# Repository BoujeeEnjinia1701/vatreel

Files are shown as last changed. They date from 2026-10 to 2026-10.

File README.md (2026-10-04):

# VatReel

     

**Area:** Advanced manufacturing · **TRL:** 3 of 9 (proof of concept on paper) · **Value-engineering target:** $1,500 USD · **Difficulty:** 2 of 5

Moves hides and yarn through pits and dye vats on a hand-cranked reel so hands never enter the liquor.

> CONCEPT, NOT FOR FABRICATION. VatReel is a TRL 3 design on paper: it has not been built or tested.

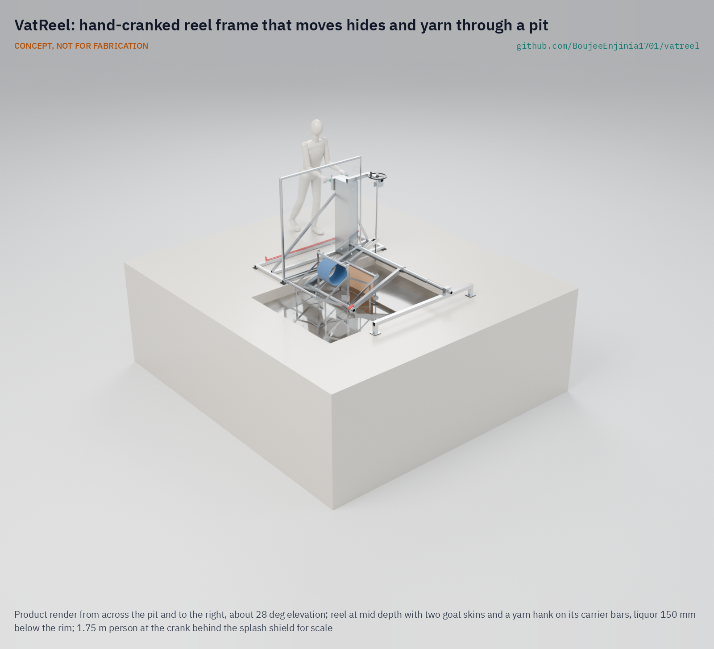
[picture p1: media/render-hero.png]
VatReel: hand-cranked reel frame that moves hides and yarn through a pit, product render


[Concept render](media/hero.png) · [Exploded view](media/exploded.png) · [Interactive 3D model](media/viewer.html) · [Concept blueprint (PDF)](media/concept-blueprint.pdf) · [General arrangement VTR-DWG-001 (PDF)](cad/drawings/VTR-DWG-001.pdf) · [Sizing note VTR-CAL-001](docs/04-calcs/01-sizing.md) · [Prototype build plan](docs/05-build-plan.md) · [Design decisions](docs/06-design-decisions.md) · [Review note](docs/REVIEW.md)

## Concept rationale

The liquor is the hazard, and the hands are the route in. Industrial dye houses solved this long ago with the winch, a reel that lifts cloth in and out of the bath, but those machines are fixed, powered and sized for factories. VatReel keeps the reel and drops everything else: a portable frame set across an existing pit or vat, a hand crank, and carriers that hold hides or hanks of yarn. The worker loads dry-side, cranks, and the reel carries the load through the liquor.

It is meant for workshops that will not buy a drum or a dyeing machine. The frame spans the pits they already have, it is built from stock sections and corrosion-resistant sheet, and every part can be cut, drilled and bolted with hand tools. Publishing it openly lets a local fabricator build it and a cooperative adapt it to its own pit sizes.

## Burning platform

In Hazaribagh, Dhaka, Human Rights Watch counted about 150 tanneries and 8,000 to 12,000 workers, and recorded workers climbing into pits to pull hides out by hand; one described acid falling on a colleague's arm so that the flesh came off ([HRW, 2012](https://www.hrw.org/report/2012/10/09/toxic-tanneries/health-repercussions-bangladeshs-hazaribagh-leather)). In Kanpur, India, tannery workers with moderate or high skin contact with chemicals were 35 times more likely to report scaling with fissures than those with low exposure, and 22 % of tannery workers reported itching and fissured hands against 7.3 % of other workers ([Kashyap et al., 2021](https://pmc.ncbi.nlm.nih.gov/articles/PMC8530047)).

The dose is not only on the skin. Among 120 tannery workers in Sialkot, Pakistan, 54 % had blood chromium above the ATSDR safety threshold and 13 % had skin rashes ([Khan et al., 2013](https://journals.sagepub.com/doi/10.1177/0748233711430974)). In hand dyeing, the UK Health and Safety Executive notes that some dyes cause allergic skin reactions and that harsh cleaning to remove colour from skin can itself cause dermatitis ([HSE](https://www.hse.gov.uk/textiles/dyes-dyeing.htm)).

## Where it could be used

### By industry

| Industry | Use |
| --- | --- |
| Small and informal tanneries | Moving hides through soaking, liming, pickling and tanning pits without workers entering or reaching into the liquor |
| Hand and craft dyeing | Carrying hanks of yarn or lengths of cloth through hot or indigo vats at an even pace |
| Heritage and tourist workshops | Keeping traditional pit processes while taking the worker's body out of the bath |
| Leather and textile supply chains | A low-cost engineering control that brands and auditors can point small suppliers to |
| Vocational and technical colleges | Teaching model for reel, gear and corrosion design in wet process industries |

### By country or region

| Country or region | Why it matters there |
| --- | --- |
| Bangladesh | Hazaribagh workers told Human Rights Watch they climb into pits and lift hides out by hand while liquor splashes their skin ([HRW, 2012](https://www.hrw.org/report/2012/10/09/toxic-tanneries/health-repercussions-bangladeshs-hazaribagh-leather)). |
| India | In Kanpur, 18 % of tannery workers reported scaling with fissures on the hands, against 3.8 % of non-tannery workers ([Kashyap et al., 2021](https://pmc.ncbi.nlm.nih.gov/articles/PMC8530047)). |
| Pakistan | More than half of the Sialkot tannery workers studied had blood chromium above the ATSDR threshold ([Khan et al., 2013](https://journals.sagepub.com/doi/10.1177/0748233711430974)). |
| Morocco | At the Chouara tannery in Fez, about 200 men work, standing thigh-deep in chromium-laden vats to move hides ([Living on Earth](https://www.loe.org/shows/segments.html?programID=14-P13-00044&segmentID=4)). |
| Nigeria | Dyers at Kano's Kofar Mata pits, traced back more than 500 years, still dip cloth again and again into deep in-ground vats of fermented indigo ([Wikipedia](https://en.wikipedia.org/wiki/Kofar_Mata_Dye_Pits)). |

## What sparked the idea

The idea came from a single line in the Human Rights Watch report on Hazaribagh. A worker described how the job is done: they get inside the pit, take the hides with their hands and throw them out, and even with gloves and boots the water splashes on their skin. Another recalled acid falling on a colleague's arm until the bone showed ([HRW, 2012](https://www.hrw.org/report/2012/10/09/toxic-tanneries/health-repercussions-bangladeshs-hazaribagh-leather)). The hazard comes from a hand task that a crank and a reel could do instead.

## Problem

In small tanneries and hand-dyeing workshops, workers reach, wade or stand in pits of acid, chromium and dye liquor to move hides and yarn through the bath. Their skin takes the dose every shift.

Full problem statement: [docs/01-problem.md](docs/01-problem.md)

## Concept

A portable hand-cranked reel frame set across a tannery pit or dye vat; workers load hides or yarn onto the reel and crank it to carry them through the liquor, so their hands never enter the bath. A stainless frame spans pits 1.0 to 2.5 m wide; the reel rides on two arms that swing on a pivot tube across the pit, and a self-locking lift screw sets how deep it dips (the lowest carrier bar 0.3 to 1.0 m below the rim) or lifts it clear. Every carrier bar comes up above the rim to be loaded with long hooks from behind a splash shield. On paper the crank needs about 90 N with a 25 kg wet load on one bar, and the parts cost about $1,437 against the $1,500 value-engineering target.

Full design precis: [docs/02-concept.md](docs/02-concept.md) · Requirements: [docs/03-requirements.md](docs/03-requirements.md)

## Key components

- Near stand (base frame and bearing tower) and far stand, joined by a telescopic pivot tube
- Arm frame swinging on the pivot tube
- Reel with six carrier bars and snap hooks
- Hand crank with a two-stage roller chain drive, 6 to 1, fully enclosed
- Ratchet and pawl brake
- Self-locking lift screw with a handwheel (in place of a lift lever)
- Splash shield
- Loading hooks

## Building the prototype

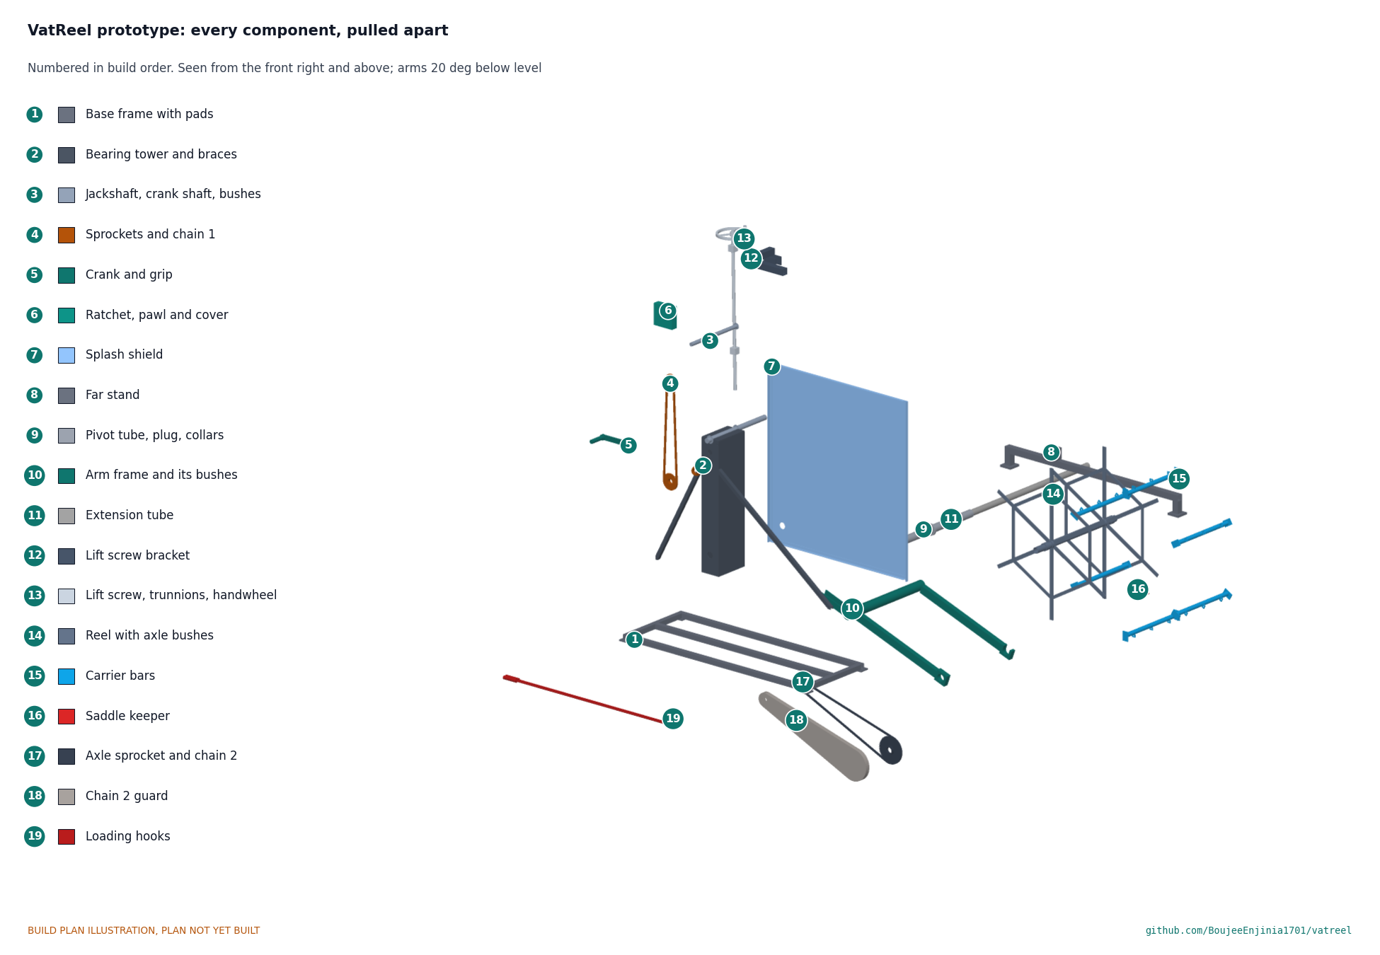
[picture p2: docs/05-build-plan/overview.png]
Every component of the VatReel prototype, pulled apart and numbered in build order


The [prototype build plan](docs/05-build-plan.md) (VTR-BLD-001, plan, not yet built) shows how to make each component and fit it to the next, in 16 making sketches, 11 joint close-ups and 13 assembly steps drawn from the model. The frame, arms and reel are sawn, drilled and welded from 304 and 316L stainless tube, bar and plate, with no casting or lathe work; the chains, sprockets, bushes and lift screw are bought. Writing the plan made the design constructable: eighteen changes, such as a torque tube joining the arms, a closed chain guard and an open saddle that lets the reel drop in without anyone reaching over the pit, are recorded in [VTR-DDR-002](docs/decisions/0002-design-for-construction.md). The parts cost about $1,437, $63 under the $1,500 value-engineering target, a hypothetical control target.

## Safety

> Published as an open engineering reference, not certified equipment. Builders and users are responsible for their own risk assessment.
>
> The reel reduces skin contact but does not remove the need for gloves, eye protection and boots.
>
> Nip points at the crank gear and reel must be guarded; loose clothing and long hair must be kept clear.
>
> The frame must not create a trip or fall hazard at the pit edge; the pit rim must be checked before placing the stands.
>
> Hot baths near 98 °C (208 °F) add a scald hazard; the splash shield and the self-locking lift are part of the design, not options, and two people are present at any bath above 60 °C.
>
> The reel and its load (up to about 55 kg) hang over the pit; the lift screw is self-locking and the ratchet holds the reel, and the chains, sprockets and ratchet are enclosed. Never reach toward the reel unless it is stopped, the ratchet is engaged and the arms are wound up. The build plan lists the safety stops (VTR-BLD-001, section 6).
>
> This design is published as an open engineering reference. It is not certified equipment.

## Repository layout

| Folder | Contents |
| --- | --- |
| `docs/` | Problem, concept, requirements, calculations and design decisions |
| `cad/src/` | build123d Python source, the source of truth for all geometry |
| `cad/step/`, `cad/stl/` | Exported models for FreeCAD, other CAD tools and printing |
| `cad/drawings/` | 2D sketches and dimensioned drawings |
| `bom/` | Bill of materials |
| `electronics/` | KiCad schematics and PCB layouts |
| `firmware/` | Microcontroller code |
| `media/` | Renders, perspectives and photos |
| `build-log/` | Dated prototyping notes |

## Documentation

Controlled documents follow the portfolio [documentation standard](.kit/STANDARDS.md). Each carries a document ID (VTR-PRC-001 for the precis), a version and a revision history. Branded PDFs are built with `python .kit/render.py` and attached to GitHub Releases when a document is tagged, for example `VTR-PRC-001/v1.0`.

## Credits

Designed by Amish Chadha at Design Molecule Labs. See [CONTRIBUTORS.md](CONTRIBUTORS.md) for roles. To cite this design, use [CITATION.cff](CITATION.cff) (GitHub shows it as "Cite this repository").

AI assistance (Claude) was used to accelerate prototype documentation and first-pass research. Design direction and all decisions are Amish Chadha's, recorded in this repository's decision records (`docs/decisions/`).

## Licenses

- **Hardware** (CAD, drawings, BOM, electronics): [CERN-OHL-S v2](LICENSE)
- **Software** (firmware, scripts, notebooks): [MIT](LICENSE-SOFTWARE)

A project of [Design Molecule Labs](https://designmolecule.com).

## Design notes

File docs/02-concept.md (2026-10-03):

---
doc_id: VTR-PRC-001
title: VatReel design precis
project: VatReel
doc_type: Precis
version: "0.3"
status: Draft
date: '2026-10-03'
author: Amish Chadha
license: CERN-OHL-S-2.0
revisions:
- version: "0.1"
  date: '2026-09-30'
  author: Amish Chadha
  change: Initial scaffold
- version: "0.2"
  date: '2026-10-03'
  author: Amish Chadha
  change: TRL 2 concept formulated with concept media; arm-carried reel, two-stage chain drive, self-locking lift; decisions under Amish's pre-approval (VTR-DDR-001)
- version: "0.3"
  date: '2026-10-03'
  author: Amish Chadha
  change: TRL 3; first-order numbers from VTR-CAL-001; constructable design (VTR-DDR-002); build plan VTR-BLD-001 and register VTR-DEC-001
---

# VatReel design precis

Moves hides and yarn through pits and dye vats on a hand-cranked reel so hands never enter the liquor.

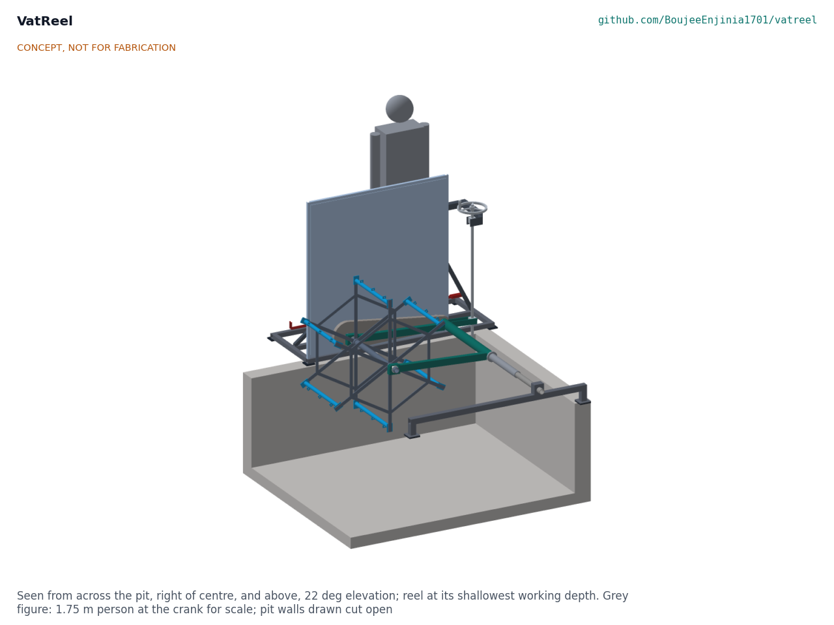
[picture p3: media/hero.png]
Figure 1. VatReel over a pit, reel at its shallowest working depth


*Figure 1. Concept render from the model: the near stand with its crank and splash shield on the operator's rim, the pivot tube across the pit to the far stand, and the reel on its arms.*

## How it works

A frame sits across the pit from rim to rim: a near stand on the operator's side and a far stand on the opposite rim, joined by a pivot tube that runs across the pit 200 mm above the rim, close to one end wall. Two arms swing on that pivot line and carry the reel at their ends; the reel's axle points across the pit, toward the operator. The operator turns a crank on the near stand, 1.0 m above the floor; two roller chains, the first inside the stand and the second in a closed case along the near arm, turn the reel at one sixth of the crank speed. Hides hang from snap hooks on six carrier bars, and hanks of yarn loop over them; as the reel turns, each bar goes down through the liquor and comes back up above the rim, where it is loaded, drained or unloaded with long hooks from behind a splash shield. A handwheel on a self-locking lift screw sets the arm angle, which sets how deep the reel dips (the lowest bar 300 to 1,000 mm below the rim) and, wound fully up, lifts every bar clear of the rim. A ratchet on the crank shaft holds the reel wherever it stops.

*Figure 2. Drive train at the worst case (estimates, VTR-CAL-001).*

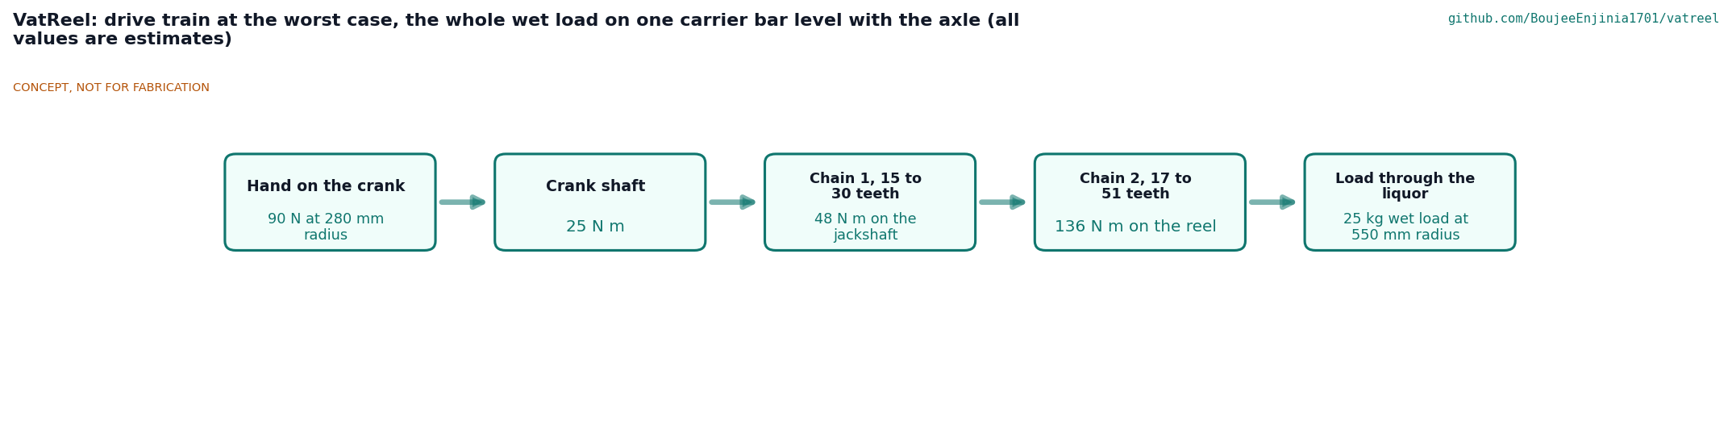
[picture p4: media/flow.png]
Figure 2. Drive train


## Components

*Table 1. Components (numbers match bom/bom.csv and the exploded view).*

| # | Component | Role |
| --- | --- | --- |
| 1, 2 | Near stand: base frame and bearing tower | Sits on the operator's rim; carries the crank, both shafts, chain 1 and the lift screw |
| 3, 4, 5 | Jackshaft, crank shaft and crank, ratchet and pawl | Turn and hold the reel |
| 6 | Splash shield | Translucent polypropylene in a stainless frame between the reel and the operator |
| 7, 8 | Lift screw bracket, lift screw, trunnions and handwheel | Set the depth and lift the reel; self-locking |
| 9, 10, 11 | Bushes, sprockets, roller chains | Two-stage 6 to 1 drive |
| 12, 13, 14 | Pivot tube, extension tube, far stand | Span pits 1.0 to 2.5 m wide |
| 16, 17 | Arm frame (torque tube and two arms), chain 2 guard | Carry the reel and enclose chain 2 |
| 18, 19 | Reel (axle and two spiders), carrier bars with snap hooks | Carry the load through the liquor |
| 15, 20, 22 | Rubber pads, loading hooks, assembly bar | Footing, hands-off loading, carrying the reel |

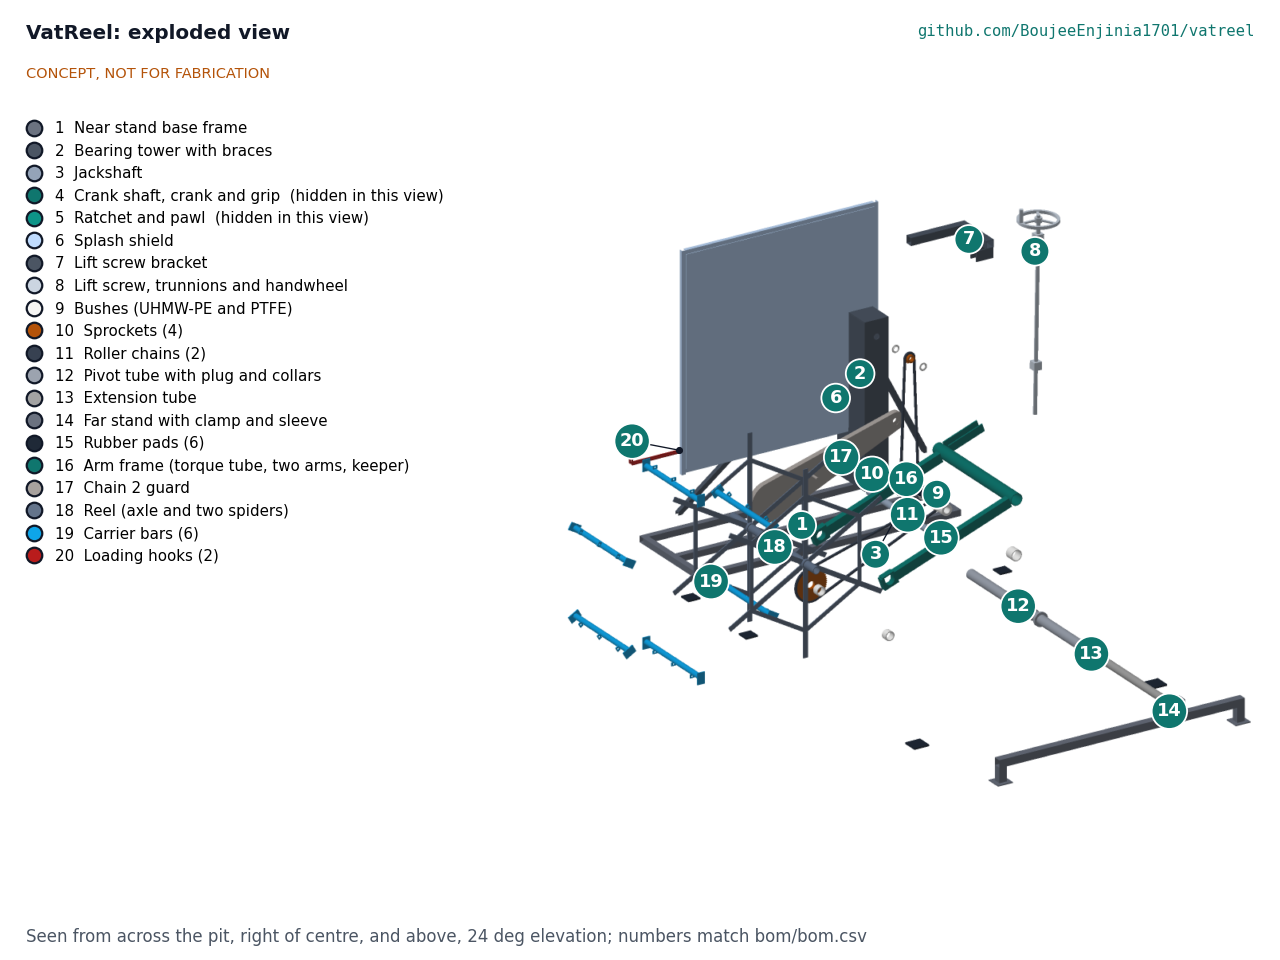
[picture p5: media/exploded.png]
Figure 3. Exploded view


*Figure 3. Exploded view with BOM numbers.*

## Key design choices

All were decided on 2026-10-03 under Amish's pre-approval and are recorded in VTR-DDR-001 (TRL 2) and VTR-DDR-002 (design for construction); VTR-DEC-001 indexes them.

- **Reel on swinging arms, not on a shaft across the pit.** A shaft spanning 1.0 to 2.5 m pits would have to telescope while turning; instead the static pivot tube telescopes and the reel stays 0.6 m long, close to the operator's rim.
- **Crank at a fixed height.** The first chain runs inside the stand from the crank to a jackshaft on the pivot line, the second along the arm, so the crank stays 1.0 m above the floor at every depth.
- **Self-locking lift screw in place of a free lift lever.** The reel and load weigh up to 55 kg; a screw cannot let them drop into a hot bath, and holds at any height.
- **Stainless throughout:** 316L for everything that goes into the liquor, 304 for the frame; glass-filled PTFE bushes in the liquor and UHMW-PE above it.
- **Everything moving is enclosed** except the reel itself, which is in the pit: chain 1 and the ratchet inside the stand, chain 2 in a closed case.

## First-order numbers

*Table 2. Key figures (estimates from VTR-CAL-001).*

| Quantity | Value | Assumption |
| --- | --- | --- |
| Reel | 1.18 m over the spokes, 0.6 m long, six bars at 550 mm radius | |
| Lowest bar below the rim | 300 to 1,000 mm, any depth between | Liquor 150 mm below the rim |
| Pits served | 1.0 to 2.52 m wide, at least 1.89 m long | Pivot 350 mm in from the end wall |
| Crank force | 90 N | 25 kg wet load all on one bar, level with the axle |
| Reel speed | 5 rpm, bars at 0.29 m/s | 30 rpm at the crank |
| Lift screw | 63 turns end to end, 79 N at the handwheel at 1.5 x | Thread friction 0.15 |
| Mass | 171 kg in all; heaviest carry 29.6 kg by two people | Model solids |
| Parts cost | USD 1,437 | Value-engineering target USD 1,500; USD 63 under |

## Patent design-arounds

From the preliminary patent, trademark and prior-art screen (not legal advice):

- Portable, manual version of the public-domain winch beck; the closest patent found, US3513672A, has expired.
- Watch items from the preliminary screen: corrosion of wetted parts and crank load. Both are addressed in VTR-CAL-001 (R6 at risk until coupon tests; crank force 90 N).

## Shared blocks

- The proposed hand capstan common block (SaltDrag, SiltHaul) is not used: the reel rises and falls, so VatReel needs its own two-stage chain drive (VTR-DDR-001).
- CalRig is the first candidate for the R5 proof-load test at TRL 4.

## Safety

> **Safety:** Published as an open engineering reference, not certified equipment. Builders and users are responsible for their own risk assessment.
>
> **Hazards.** Corrosive liquors (lime, sulphides, acids, chromium salts) and, in dyeing, baths near 98 °C (208 °F) that scald; an open pit edge with wet floors; moving machinery (the reel, two roller chains, a ratchet and a lift screw); a 55 kg reel and load hanging over the pit; lifts of up to 30 kg by two people during setup.
>
> **What the design does about them.** Hands stay out of the liquor: every bar comes up above the rim to be loaded with long hooks. The splash shield stands between the reel and the operator. The chains, sprockets and ratchet are enclosed. The lift screw is self-locking and the ratchet holds the reel, so nothing falls when the handwheel or crank is let go. The stands sit back from the pit edge on rubber pads.
>
> **What the user must still do.** Wear gloves, eye protection and boots; keep loose clothing and long hair clear of the crank; never reach over the shield or into the pit while the reel can turn; do not work alone at a hot bath; check the pit rim before placing the stands. The shield is not a guardrail.
>
> This design is published as an open engineering reference. It is not certified equipment.

## Next step

TRL 3 is reached on paper. The recommended next step, when the portfolio phase allows it, is TRL 4: build the prototype to VTR-BLD-001 and test it on a water-filled tank, then with the first co-design partner.

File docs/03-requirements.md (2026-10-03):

---
doc_id: VTR-REQ-001
title: VatReel requirements
project: VatReel
doc_type: Requirements
version: "0.3"
status: Draft
date: '2026-10-03'
author: Amish Chadha
license: CERN-OHL-S-2.0
revisions:
- version: "0.1"
  date: '2026-09-30'
  author: Amish Chadha
  change: Initial scaffold
- version: "0.2"
  date: '2026-10-03'
  author: Amish Chadha
  change: TRL 2 review; targets confirmed under Amish's pre-approval (VTR-DDR-001); R11 lift and R12 guarding added; concept status for each requirement
- version: "0.3"
  date: '2026-10-03'
  author: Amish Chadha
  change: TRL 3 status on paper from VTR-CAL-001 for the constructable design; pit length added to the assumptions; R10 against the value-engineering target
---

# VatReel requirements

Twelve measurable requirements. The status column gives the result on paper from the calculation note VTR-CAL-001 on the constructable design; every requirement is verified by test at TRL 4 or later. Ten are met on paper, R6 (corrosion) is at risk and R8 (portability) is not met as written.

*Table 1. Requirements.*

| ID | Requirement | Target | Verification (TRL 4 or later) | Status on paper (VTR-CAL-001) |
| --- | --- | --- | --- | --- |
| R1 | Operator loads, runs and unloads a batch without any hand entering the liquor | 0 hand contacts with liquor per batch | Observed trial with workers over at least 10 batches | Met on paper: the top carrier bar is 100 to 800 mm above the rim at every working depth; loading with long hooks |
| R2 | Handle force to turn the loaded reel | 100 N (22 lbf) or less with a 25 kg (55 lb) wet load | Spring balance at the handle on a water-filled test tank | Met: 90 N with the whole load on one bar |
| R3 | Width of pits and vats served | 1.0 to 2.5 m (3 to 8 ft), adjustable | Fit check on test frames of minimum and maximum width | Met: 1.0 to 2.52 m |
| R4 | Immersion depth of the lowest carrier bar below the rim | Adjustable 0.3 to 1.0 m (1 to 3.3 ft) | Measurement at both settings | Met: any depth from 0.30 to 1.00 m |
| R5 | Holding brake | Holds the rated load at any position with 1.5 times rated load applied, no slip | CalRig proof-load test | Met on paper: ratchet stresses under 13 MPa |
| R6 | Corrosion resistance of wetted parts | No structural corrosion after 500 h immersion in sample liming, pickling and chrome liquors | Coupon immersion test and inspection | At risk: shown only by material choice; stainless chain 2 in chloride pickle is the weak point |
| R7 | Heat tolerance for dye use | Operates in baths up to 98 °C (208 °F) with no deformation of reel or carriers | Hot-bath trial with temperature log | Met on paper: all materials rated |
| R8 | Portability | Each module 25 kg (55 lb) or less; two people set up in 15 min or less | Weigh modules; timed setup trial | **Not met:** two modules 27.1 and 29.6 kg (two-person carries, 14.8 kg each at most); setup about 29 min |
| R9 | Splash control at the crank position | No liquor droplets reaching the operator at normal cranking speed | Indicator paper on the operator's apron during trials | Met on paper: every sight line from the reel to the eye is blocked |
| R10 | Cost | Value-engineering target USD 1,500 for prototype parts | Costed bill of materials | USD 1,437, USD 63 under the value-engineering target |
| R11 | Lift and depth setting | Self-locking: holds the reel at any height with no brake applied; 100 N or less at the handwheel at 1.5 x load; lifts every carrier bar above the rim | Proof-load and handwheel force test | Met on paper: self-locking thread; 79 N; lowest bar 149 mm above the rim when lifted |
| R12 | Guarding of moving parts | Chains, sprockets and ratchet enclosed; no nip point reachable from the operator position | Inspection against ISO 13857 by a competent person | Met on paper by enclosure; openings to check |

## Assumptions

- Pit rims are strong enough to carry the stands and load (under 600 N per stand); to be checked on site.
- Pits are at least 1.9 m (6.2 ft) long so the reel can swing; the arm pivot sits 350 mm in from the pit's end wall.
- The liquor stands about 150 mm below the rim; the rim is level with the floor.
- Hides can be toggled or hooked at one edge and yarn hanks looped over a bar so they stay on the reel as it turns.
- Existing process times and chemistry stay as they are; VatReel changes only how the load moves.
- A reel speed that a person can crank (about 5 rpm) is slow enough for even treatment.

> **Safety:** These requirements cover moving machinery beside open pits of corrosive and hot liquor. Meeting them on paper does not make the design safe to use; gloves, eye protection and boots stay in use, and every site needs its own risk assessment.

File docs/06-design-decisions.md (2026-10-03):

---
doc_id: VTR-DEC-001
title: VatReel design decisions register
project: VatReel
doc_type: Design decisions register
version: "0.1"
status: Draft
date: '2026-10-03'
author: Amish Chadha
license: CERN-OHL-S-2.0
revisions:
- version: "0.1"
  date: '2026-10-03'
  author: Amish Chadha
  change: Register opened; every decision made under Amish's 2026-10-03 pre-approval
---

# VatReel design decisions register

Every design decision still to be made, and every decision made, in one place. Each decision is argued in full in its decision record under `docs/decisions/`; this register is the index Amish works from. The build plan (`docs/05-build-plan.md`) describes the design as it stands and does not list decisions.

## Open decisions

None. All decisions were made under Amish's 2026-10-03 pre-approval.

## To confirm when parts are bought

| # | What to confirm | Why it matters | Source |
| --- | --- | --- | --- |
| 1 | The stainless 17 and 51 tooth sprockets come bored 40 and 48.3 with hubs long enough for a roll pin | Sets the jackshaft and axle drilling and the guard case clearance | VTR-DDR-002, change 2 |
| 2 | Pitting of the 304 chain 2 and 316L coupons in the partner's pickling and chrome liquors | R6 is at risk until shown; chain 2 may move to a 316 chain or a polymer drive | VTR-CAL-001, section 11 |
| 3 | The bronze Tr24 x 5 nut bought is single start and runs self-locking on the rod under load | R11 depends on it; a two-start nut would not lock | VTR-CAL-001, section 6 |
| 4 | Running clearance and creep of the glass-filled PTFE axle bushes in 98 °C water | R7; sets the bush bore | VTR-CAL-001, section 11 |
| 5 | Temperature at the UHMW-PE bushes above a hot bath | UHMW-PE is good to about 80 °C; PTFE bushes there if it runs hotter | VTR-CAL-001, section 11 |
| 6 | The first partner's pit: rim strength, width, length (at least 1.9 m), liquor level and end wall | The pivot sits 350 in from the end wall; the stands bear on the rims | VTR-REQ-001, assumptions |
| 7 | How the partner's workers hang hides (toggles through a punched hole) and loop yarn hanks on the bars | Sets the eye tab spacing and the snap hook size | VTR-DDR-001, item 7 |

## Value engineering

Value-engineering target: USD 1,500 (a hypothetical control target, not a limit). Estimated cost of the constructable design: USD 1,437 (USD 63 under the target). Main cost drivers and savings worth trying:

- Stainless is most of the cost: the reel and carrier bars (USD 246), the lift screw set (USD 130) and the bearing tower (USD 125). The frame (base, tower, shield, far stand, tubes) is 304; only parts that enter the liquor are 316L.
- Bought drive parts (sprockets USD 97, chains USD 62, bushes USD 63) are about 15 % of the cost; the stainless pair on the arm costs twice the plated pair in the tower.
- Making the design constructable added about USD 40: the closed chain 2 case, the ratchet cover and the wider splash shield. They are guarding, so savings are sought elsewhere.
- Savings worth trying: a hot-dip galvanized mild steel near stand and far stand where only splash reaches (about USD 120 less, to be weighed against corrosion in lime and acid splash); a bought cast iron handwheel in place of a stainless one; carrier bar end plates cut from offcuts.

## Decisions made

| Date | Decision | Decided by | Record |
| --- | --- | --- | --- |
| 2026-10-03 | Reel on two arms swinging on a static telescopic pivot tube across the pit, not on a turning shaft between end stands | Amish, pre-approval: "I pre-approve the batch runs along with any recommendations you come up with." | VTR-DDR-001, item 1 |
| 2026-10-03 | Reel axis across the pit, pointing at the operator; reel 1.18 m over the spokes, 0.6 m long; pits at least 1.9 m long | Amish, pre-approval (as above) | VTR-DDR-001, item 2 |
| 2026-10-03 | Self-locking lift screw with a handwheel in place of a free lift lever (safety, conservative) | Amish, pre-approval (as above) | VTR-DDR-001, item 3 |
| 2026-10-03 | Two-stage roller chain drive, 6 to 1, crank fixed 1.0 m above the floor | Amish, pre-approval (as above) | VTR-DDR-001, item 4 |
| 2026-10-03 | Ratchet and pawl on the crank shaft as the holding brake | Amish, pre-approval (as above) | VTR-DDR-001, item 5 |
| 2026-10-03 | 304 frame, 316L wetted parts, PTFE bushes in the liquor, UHMW-PE above it | Amish, pre-approval (as above) | VTR-DDR-001, item 6 |
| 2026-10-03 | Carrier bars with eye tabs and stainless snap hooks; yarn looped over the bars | Amish, pre-approval (as above) | VTR-DDR-001, item 7 |
| 2026-10-03 | Enclose both chains, the sprockets and the ratchet; add R12 (safety, conservative) | Amish, pre-approval (as above) | VTR-DDR-001, item 8 |
| 2026-10-03 | Two people present at any bath above 60 °C (safety, conservative) | Amish, pre-approval (as above) | VTR-DDR-001, item 9 |
| 2026-10-03 | Own chain drive rather than the hand capstan block; CalRig the first candidate for the proof load | Amish, pre-approval (as above) | VTR-DDR-001, item 10 |
| 2026-10-03 | R11 (lift) and R12 (guarding) added; pit length added to the assumptions | Amish, pre-approval (as above) | VTR-DDR-001, item 11 |
| 2026-10-03 | First co-design candidate to approach: a worker health NGO or tannery association in the Kanpur leather cluster, India (not agreed) | Amish, pre-approval (as above) | VTR-DDR-001, item 12 |
| 2026-10-03 | Value-engineering target kept at USD 1,500 | Amish, pre-approval: "I also accept any cost overruns or variations from the assumed scope cost." | VTR-DDR-001, item 13 |
| 2026-10-03 | Design for construction: torque tube, sprocket sizes, closed chain 2 case, ratchet cover, open far saddle with keeper, plug on the jackshaft tip, extension tube and clamp, wider shield and the other changes in VTR-DDR-002 | Amish, pre-approval (as above) | VTR-DDR-002 |
| 2026-10-03 | R8 accepted as not met for the prototype: two modules of 27.1 and 29.6 kg carried by two people (14.8 kg each at most); first setup about 29 minutes | Amish, pre-approval (as above) | VTR-CAL-001, section 9 |

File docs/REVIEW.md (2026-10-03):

# Review note: VatReel

## Session 2026-10-03: TRL 1 to TRL 3 under Amish's pre-approval (kit 1.7.0)

Amish Chadha, 2026-10-03: "start with the first 14 repos from the list of 29 projects. I pre-approve the batch runs along with any recommendations you come up with. I also accept any cost overruns or variations from the assumed scope cost." Every choice below is therefore decided, not proposed, and recorded in VTR-DDR-001, VTR-DDR-002 and the register VTR-DEC-001. Nothing was built or tested.

Kit 1.7.0 installed (`.kit/`, `.claude/commands/`, root `CLAUDE.md` from `.kit/CLAUDE.md`; `.kit/PHASE.yaml` as installed).

### TRL 2: concept formulated

**What was done**

- `docs/01-problem.md` (VTR-PRB-001 v0.2): pit length and liquor level added to the environment; first co-design candidate; questions for the site survey; safety note.
- `docs/03-requirements.md` (VTR-REQ-001 v0.2): R1 to R10 confirmed; R11 (self-locking lift) and R12 (guarding) added.
- `docs/02-concept.md` (VTR-PRC-001 v0.2): how it works, components, key design choices, first-order numbers, safety.
- Concept model and media: `cad/src/concept_media.py` generates `media/hero.png`, `media/concept-blueprint.png` and `.pdf`, `media/model.glb`, `media/viewer.html`, `media/cutaway.png`, `media/exploded.png` and `media/flow.png` (drive train; values marked as estimates). The media were regenerated from the TRL 3 constructable model below.
- `bom/bom.csv` with the main components and indicative costs.

**Results.** The scaffold's concept (end stands on opposite rims carrying a reel shaft across the pit, with a lift lever) could not span 1.0 to 2.5 m without a turning telescopic shaft over the pit, and a lift lever could not lift a 55 kg reel and load through the 1.3 m needed. The formulated concept carries the reel on two arms that swing on a static telescopic pivot tube across the pit; a two-stage chain keeps the crank at 1.0 m at every depth; a self-locking screw sets the arm angle.

**Requirements not met at TRL 2.** None identified at concept level; R8 (masses) was flagged for the TRL 3 check.

**Decisions made under the pre-approval (VTR-DDR-001).** Reel on swinging arms; reel axis across the pit; self-locking lift screw in place of a lever (safety, conservative); two-stage chain drive 6 to 1; ratchet brake; 304 frame and 316L wetted parts with PTFE and UHMW-PE bushes; carrier bars with snap hooks; all chains and the ratchet enclosed (safety, conservative); two people at any bath above 60 °C (safety, conservative); own drive, not the hand capstan block, and CalRig as the first proof-load candidate; R11 and R12 added; first co-design candidate a worker health NGO or tannery association in the Kanpur leather cluster (a candidate, not agreed); value-engineering target kept at USD 1,500.

**Safety concerns.** Corrosive and hot liquor, the open pit edge, moving machinery, a 55 kg suspended load over the pit.

### TRL 3: proof of concept on paper

**What was done**

- `docs/04-calcs/01-sizing.md` (VTR-CAL-001 v0.2) and `docs/04-calcs/sizing.py`: depth and positions, spans, drive, brake, lift screw, structure at 1.5 x, support, masses and setup time, splash sight lines, heat and corrosion, cost, results against every requirement.
- `cad/src/model.py`: parametric build123d model, 45 components, with fit checks (`--check`: no overlaps, every joint touching, clear of the frame and pit walls at the lifted, shallowest and deepest positions: PASS). STEP and STL in `cad/step/` and `cad/stl/` (assembly, near arm, far arm, reel, carrier bars, bearing tower, far stand).
- `cad/src/sheets.py`: general arrangement VTR-DWG-001 Rev P2.
- `bom/bom.csv`: 23 lines, every line priced with a supplier type.
- `cad/src/product_model.py` (appearance model) and render scenes for the Mac: hero, exploded and detail exported with `.kit/export_views.py`.
- Constructable design and build plan: `docs/decisions/0002-design-for-construction.md` (VTR-DDR-002), `cad/src/build_plan_media.py`, `docs/05-build-plan.md` (VTR-BLD-001) with 16 making sketches (`cad/drawings/VTR-DWG-101` to `116`), 11 joint close-ups and 13 step pictures in `docs/05-build-plan/`; `docs/06-design-decisions.md` (VTR-DEC-001).
- `project.yaml`: trl 3, trl_target 3, design_state constructable, trl_evidence listing the files. README updated (hero render first, build plan link and section).

**Key results (VTR-CAL-001).**

| Quantity | Value |
| --- | --- |
| Lowest carrier bar below the rim | 300 to 1,000 mm, any depth; top bar 100 to 800 mm above the rim |
| Pits served | 1.0 to 2.52 m wide, at least 1.89 m long |
| Crank force, 25 kg on one bar | 90 N (R2 100 N) |
| Ratchet at 1.5 x | 602 N tooth force, 12.5 MPa |
| Lift screw | Self-locking (lead 4.23 deg, friction 8.83 deg); 63 turns; 79 N at the handwheel at 1.5 x; buckling factor 2.7 |
| Lowest margin at 1.5 x | Spoke 106 MPa, factor 1.6 on yield; bracket 118 MPa, factor 1.7 |
| Mass | 171 kg; heaviest carry 29.6 kg by two people |
| Cost | Value-engineering target: USD 1,500. Estimated cost of the constructable design: USD 1,437 (USD 63 under the target) |

**Requirements not met.**

- **R8 (portability): not met as written.** Two modules weigh 27.1 kg (pivot tube with arm frame) and 29.6 kg (reel with bars); both are two-person carries at 14.8 kg each at most. First setup is about 29 minutes against 15. Accepted for the prototype under the pre-approval (VTR-DEC-001).
- **R6 (corrosion): at risk.** Only a coupon test can show it; the 304 chain 2 in chloride pickling liquor is the weak point.

**Decisions made under the pre-approval.** All TRL 2 decisions above (VTR-DDR-001); the eighteen design-for-construction changes (VTR-DDR-002); R8 accepted as not met for the prototype. Open decisions: none. Seven items to confirm when parts are bought are in VTR-DEC-001.

**Build plan findings (design changes made for construction, VTR-DDR-002).**

1. The arm tie tube would have bent at about 280 MPa: replaced by a torque tube round the pivot line (29 MPa).
2. 12-tooth sprockets cannot be bored 30 or 40 mm: 15/30 and 17/51 teeth, ratio still 6 to 1.
3. Chain 2 guard plate replaced by a closed case.
4. Tower bottom closed; ratchet and pawl under a cover with the release lever outside.
5. Far bearing is an open saddle with a keeper, so the reel drops in without anyone reaching 0.9 m over the pit; near bearing split with a bolted cap.
6. Pivot tube carried on the jackshaft tip by a plug; two collars locate the arm frame.
7. Extension tube 1.55 m pinned inside the pivot tube; far stand clamps through a split sleeve; spans 1.0 to 2.52 m.
8. Splash shield widened to 1.32 m and lowered to 60 mm with a hole for the jackshaft; base frame lengthened to 1.75 m to carry it.
9. Tower braces bolted and lowered (tower 23.2 kg; clears the ratchet cover).
10. Spiders on hub sleeves with hexagon ties; carrier bars bolted with end plates and eye tabs; axle sprocket hub moved to the wall side.
11. 1.5 m loading hooks stored on the base; a 3.6 m assembly bar through the hollow axle for carrying the reel; a thirteen-step assembly order.

**Appearance model deviations (`cad/src/product_model.py`).** Added for the renders only: snap hooks on the eye tabs, two goat skins and a yarn hank hanging from three bars, the pit cut into a concrete floor with brown liquor 150 mm below the rim, and a 1.75 m mannequin at the crank. Every main dimension comes from `model.py`.

**Render scenes.** `python3 .kit/export_views.py /home/claude/renders/vatreel` wrote `vatreel__hero`, `vatreel__exploded` and `vatreel__detail` (.npz and .json each) and `vatreel__jobs.json`. Photoreal renders, captions and cards are made on Amish's Mac; until then `media/render-hero.png` is missing and the check warns.

**Safety concerns.**

- Corrosive liquor and hot dye baths (to 98 °C): hands stay out by design, but gloves, eye protection and boots stay in use; two people at hot baths.
- Open pit edge: the stands sit back from the edge; nobody works from boards or the frame over the pit; the shield is not a guardrail.
- Moving machinery: chains, sprockets and ratchet enclosed; the reel itself is open in the pit and is never approached unless stopped, ratcheted and wound up. The guard openings still need an ISO 13857 check by a competent person (R12, TRL 4).
- Suspended load: the self-locking screw and the ratchet hold the reel; the far keeper and near cap must be closed before use.
- Setup lifts of up to 15 kg per person over a pit edge; stainless weld fume during the build.

**Recommended next step.** The design is ready for TRL 4 when the portfolio phase allows it: build to VTR-BLD-001, run the first checks over a water tank, coupon-test the wetted materials in the partner's liquors, then trial with the first co-design partner. Suggestions for later, not in the repo: a lighter reel (25 x 5 spokes, if a finer check that counts the tie ring allows it) to bring the reel under 25 kg; galvanized mild steel stands to save about USD 120.

## Session 2026-09-30: scaffolded

### What was done

- Repository created from kit 1.6.0 at TRL 1, target TRL 2.
- `docs/01-problem.md` (VTR-PRB-001 v0.1): problem with cited evidence, users, environment, constraints, prior work, open questions.
- `docs/02-concept.md` (VTR-PRC-001 v0.1): how it works, components, patent design-arounds, shared blocks, safety.
- `docs/03-requirements.md` (VTR-REQ-001 v0.1): 10 proposed requirements.
- `README.md` with concept rationale, burning platform, where it could be used, and what sparked the idea.

## 2026-10-03: photoreal renders

Rendered with Blender Cycles on Amish's Mac from `cad/src/product_model.py`; captioned with `.kit/photo_caption.py`; `media/card.png` and `media/social-preview.png` made with `.kit/cards.py`. Views: hero, exploded, detail. image_qc passes and `render.py --check` has no FAIL.

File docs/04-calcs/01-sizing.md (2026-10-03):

---
doc_id: VTR-CAL-001
title: VatReel sizing and first-principles checks
project: VatReel
doc_type: Calculation note
version: "0.2"
status: Draft
date: '2026-10-03'
author: Amish Chadha
license: CERN-OHL-S-2.0
revisions:
- version: "0.1"
  date: '2026-10-03'
  author: Amish Chadha
  change: First TRL 3 sizing note against every requirement (depth, span, drive, brake, lift, structure, masses, splash, cost)
- version: "0.2"
  date: '2026-10-03'
  author: Amish Chadha
  change: Rerun on the constructable design (VTR-DDR-002); torque tube, guard case, wider shield, extension tube 1.55 m; cost USD 1,437
---

# VatReel sizing and first-principles checks

On paper VatReel does what it is meant to do: every carrier bar comes up above the rim at every working depth, so hides and yarn are loaded and unloaded without a hand in the liquor; the reel turns with about 90 N at the crank with the whole 25 kg wet load on one bar; the lowest bar can be set anywhere from 300 to 1,000 mm below the rim; and the self-locking lift screw holds the reel at any height and lifts every bar clear of the rim. Ten of the twelve requirements are met on paper. R8 (portability) is not met as written: two modules weigh 27.1 and 29.6 kg, so they are two-person carries, and first setup is estimated at about 29 minutes against 15. R6 (corrosion) can only be shown by a coupon test and is at risk for the stainless chain in chloride pickling liquor. The parts cost about USD 1,437 against the USD 1,500 value-engineering target, USD 63 under it.

Every number in this note is printed by `docs/04-calcs/sizing.py` (run from the repo root: `python docs/04-calcs/sizing.py`). The script reads the geometry from `PARAMS` and `geometry()` in `cad/src/model.py`, takes masses from the model solids and reads prices from `bom/bom.csv`, so the model, the drawing VTR-DWG-001, the BOM and this note agree. All values are first-principles estimates; nothing here is measured.

> **Safety:** VatReel is moving machinery used beside open pits of corrosive and, in dyeing, hot liquor (up to 98 °C (208 °F)). The checks below are paper checks of strength and reach; they do not replace a risk assessment of the site, the pit edge or the process chemistry.

## 1. Assumptions

*Table 1. Inputs. All are assumptions for a paper design.*

| Input | Value | Basis |
| --- | --- | --- |
| Wet load | 25 kg of hides or yarn with the liquor they carry | R2 |
| Worst case for torque | Whole wet load on one carrier bar level with the axle; buoyancy and drag ignored | Conservative |
| Proof factor | 1.5 x the rated load; stresses held to yield / 1.5 at proof | R5 |
| Pit | 1.0 to 2.5 m wide, at least 1.9 m long, rim level with the floor, liquor 150 mm below the rim | VTR-PRB-001; site survey to confirm |
| Materials | 316L tube and sheet, yield 170 MPa; 316 bar and 304 sections, yield 205 MPa; E = 193 GPa | Minimum 0.2 % proof stresses |
| Chain | ISO 606 08B-1, minimum tensile strength 18.0 kN | Standard |
| Chain stage efficiency | 0.95 per stage including its plain bearings | Typical |
| Axle bearings | Glass-filled PTFE on stainless, friction 0.10 wet | Typical |
| Lift screw | Tr24 x 5 single start, bronze nut, thread friction 0.15 (wet, dirty), thrust ball bearing at the top | Conservative |
| Operator | Eye 1,600 mm high, 1,150 mm behind the near pit edge, at the crank | 1.75 m person |
| Cranking speed | 30 rpm | Steady hand cranking |
| Prices (2026) | 304 stainless USD 4.50/kg, 316 and 316L USD 6.50/kg; bought parts at regional retail estimates | Indicative, not quotes |

## 2. Depth and positions (R1, R4, R11)

The arms swing on the pivot line 200 mm above the rim; the arm angle sets the depth. Every working position keeps the top carrier bar above the rim, which is where loads are hung and taken off.

*Table 2. Arm positions (heights from the rim; + is up; mm).*

| Position | Arm angle below level | Axle height | Lowest bar | Top bar | Reel extends along the pit | Screw length |
| --- | --- | --- | --- | --- | --- | --- |
| Lifted | -33.7 deg | +699 | +149 | +1,249 | 159 to 1,339 | 1,020 |
| Shallowest working | -3.2 deg | +250 | -300 | +800 | 309 to 1,489 | 894 |
| Mid depth (modelled) | +20.0 deg | -108 | -658 | +442 | 256 to 1,436 | 795 |
| Deepest working | +46.2 deg | -450 | -1,000 | +100 | 33 to 1,213 | 704 |

R4 is met: the lowest bar can be set anywhere from 300 to 1,000 mm below the rim. R1 is met on paper: the top bar is 100 to 800 mm above the rim at every working depth, and lifted, every bar is at least 149 mm above it. The model's fit check confirms that nothing collides with the frame or the pit walls at the lifted, shallowest and deepest positions (`python cad/src/model.py --check`).

## 3. Spans (R3)

The pivot tube alone reaches pits 1,000 to 1,220 mm wide; with the extension tube pinned inside it, 1,220 to 2,520 mm. R3 is met. The reel needs a pit at least 1,890 mm long (the pivot 350 mm in from the end wall, plus the reel swing and 50 mm clear); this is added to the assumptions in VTR-REQ-001. The drum is 600 mm long and the far end of the arm frame is 955 mm in from the near edge, so a 1.0 m pit leaves 45 mm clear.

## 4. Drive (R2)

*Table 3. Drive at the worst case.*

| Item | Value |
| --- | --- |
| Load torque on the reel (25 kg at 550 mm) | 134.9 N m |
| Axle bearing friction | 1.3 N m |
| Ratio, chain 1 (15 to 30 teeth) x chain 2 (17 to 51 teeth) | 6.0 |
| Torque on the jackshaft | 47.8 N m |
| Torque on the crank shaft | 25.1 N m |
| Hand force at 280 mm crank radius | **90 N** |
| Chain 1 tension; factor on breaking load at proof | 823 N; 15 |
| Chain 2 tension; factor on breaking load at proof | 1,383 N; 9 |
| At 30 rpm on the crank: reel speed; carrier bar speed; time per turn | 5.0 rpm; 0.29 m/s; 12 s |

R2 is met: 90 N against 100 N in the worst case. With loads spread round the reel the torque is a fraction of this.

## 5. Holding brake (R5)

The ratchet on the crank shaft holds 1.5 x the worst load torque with no credit for chain friction: 33.7 N m on the crank shaft, a tooth force of 602 N, 12.5 MPa bearing on the 8 mm tooth, 5.3 MPa shear in the 12 mm pawl pin, and 6.4 MPa (crank shaft) and 5.4 MPa (jackshaft) in torsion. R5 is met on paper with large margins; the CalRig proof-load test is TRL 4 work.

## 6. Lift screw (R11)

The Tr24 x 5 thread has a lead angle of 4.23 deg against a friction angle of 8.83 deg, so it is self-locking: the reel cannot run down on its own. Its stroke is 316 mm, 63 turns from lifted to deepest.

*Table 4. Lift screw at 1.5 x the load moment.*

| Position | Screw length (mm) | Lever arm (mm) | Moment (N m) | Screw force (N) | Torque (N m) | Handwheel rim force (N) |
| --- | --- | --- | --- | --- | --- | --- |
| Lifted | 1,020 | 214 | 704 | 3,298 | 8.5 | 68 |
| Shallowest | 894 | 250 | 845 | 3,386 | 8.7 | 70 |
| Mid depth | 795 | 233 | 795 | 3,410 | 8.8 | 70 |
| Deepest | 704 | 152 | 586 | 3,847 | 9.9 | 79 |

The screw is in compression; its Euler load at the longest length is 10.5 kN against 3.85 kN (factor 2.7), and the root stress is 14.3 MPa. R11 is met on paper.

## 7. Structure at the proof load

*Table 5. Stresses at 1.5 x, against yield / 1.5.*

| Part | Load case | Stress (MPa) | Yield (MPa) | Factor on yield |
| --- | --- | --- | --- | --- |
| Carrier bar | Whole load spread along one bar, simply supported | 19 | 170 | 9.2 |
| Spoke | Half that load at the tip, no help from the hexagon ties | 106 | 170 | 1.6 |
| Reel axle | Reel and load at mid span plus torque | 43 | 170 | 4.0 |
| Arm | Half the reel and load at its end, arm level | 40 | 170 | 4.3 |
| Torque tube | Far arm's moment carried to the lever | 29 | 170 | 5.8 |
| Jackshaft | Overhang carrying the near bush and the pivot tube plug (242 N m) | 39 | 205 | 5.3 |
| Pivot tube | 2.5 m pit, far bush load between plug and clamp (299 N m) | 25 | 205 | 8.2 |
| Lift screw bracket | 3.85 kN at 255 mm | 118 | 205 | 1.7 |

Every part is within yield / 1.5 at the proof load. The spoke and the bracket have the smallest margins; the spoke figure ignores the ties, which share the load.

## 8. Support

The centre of the reel stays well inside the feet of both stands (451 mm at the lifted position, 577 mm at the deepest). With the reel loaded, the near stand carries 316 to 550 N and the far stand 471 to 237 N across pits 1.0 to 2.5 m wide; both are small loads on a sound rim.

## 9. Masses and setup (R8)

*Table 6. Masses of the parts carried to the pit (kg).*

| Module | Mass | Carry |
| --- | --- | --- |
| Near stand base frame with pads and hooks | 19.5 | One person |
| Bearing tower, bare | 23.2 | One person |
| Shafts, sprockets, chain 1, crank and ratchet (fitted in place) | 16.2 | Several pieces |
| Tower braces | 4.0 | One person |
| Splash shield | 12.1 | One person |
| Lift screw bracket | 3.9 | One person |
| Lift screw with trunnions and handwheel | 8.6 | One person |
| Pivot tube with the arm frame on it | 27.1 | Two people, 13.5 each |
| Extension tube | 6.3 | One person |
| Far stand | 12.4 | One person |
| Chain 2 with its guard | 8.2 | One person |
| Reel with carrier bars and axle sprocket | 29.6 | Two people, 14.8 each |
| **Total** | **171.2** | |

R8 is not met as written: two modules exceed 25 kg, though no person carries more than 23.2 kg. First setup is estimated at 29 minutes over ten steps (`setup_time()` in the script) against 15; moving between pits of the same width is quicker. Both are recorded as decided limits in VTR-DEC-001.

## 10. Splash (R9)

All 156 straight lines checked from the top half of the reel, at four depths and three positions along it, to the operator's eye pass through the splash shield (crossings 89 to 1,427 mm above the rim, inside the shield's 60 to 1,450 mm) or into the near pit wall. R9 is met on paper; droplets do not travel in straight lines, so the indicator paper trial remains the test (TRL 4).

## 11. Heat and corrosion (R6, R7)

*Table 7. Material limits.*

| Material | Where | Limit | Against 98 °C liquor |
| --- | --- | --- | --- |
| 316L stainless | Reel, arms, wetted parts | Well above 98 °C | Met |
| Glass-filled PTFE | Axle bushes in the liquor | About 260 °C | Met |
| UHMW-PE | Bushes above the liquor | About 80 °C continuous | Met if splash only; temperature at the bushes to confirm |
| Polypropylene | Shield sheet | About 100 °C | Met (splash only) |
| EPDM | Pads | About 120 °C | Met |

R7 is met on paper. R6 cannot be shown by calculation: 316L resists lime and sulphide liquors and chrome liquors well, but chloride pickling liquor can pit stainless steel, and the 304 chain 2 is the weakest part. It is marked at risk until the coupon immersion test.

## 12. Cost (R10)

The priced BOM totals USD 1,437. Value-engineering target: USD 1,500. Estimated cost of the constructable design: USD 1,437 (USD 63 under the target).

## 13. Results against the requirements

*Table 8. Requirements on paper.*

| ID | Requirement | Result on paper | Status |
| --- | --- | --- | --- |
| R1 | No hand in the liquor | Top bar 100 to 800 mm above the rim at every working depth; loaded with hooks | Met on paper |
| R2 | Crank force 100 N or less, 25 kg | 90 N worst case | Met |
| R3 | Pits 1.0 to 2.5 m wide | 1.0 to 2.52 m; pit at least 1.89 m long | Met |
| R4 | Lowest carrier 0.3 to 1.0 m deep | 0.30 to 1.00 m, any depth between | Met |
| R5 | Brake holds 1.5 x | Ratchet stresses under 13 MPa; self-locking lift screw | Met on paper |
| R6 | Corrosion, 500 h in three liquors | Material choice only | At risk (chain 2 in pickle) |
| R7 | 98 °C baths | All materials rated | Met on paper |
| R8 | Modules 25 kg or less; setup 15 min | Two modules 27.1 and 29.6 kg (two-person carries); about 29 min | **Not met** |
| R9 | No droplets reach the operator | All sight lines blocked | Met on paper |
| R10 | Cost against the USD 1,500 target | USD 1,437 | USD 63 under the target |
| R11 | Self-locking lift, 100 N or less | 79 N at 1.5 x; self-locking | Met on paper |
| R12 | Moving parts guarded | Chains, sprockets and ratchet enclosed | Met on paper; openings to check |

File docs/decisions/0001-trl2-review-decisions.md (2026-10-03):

---
doc_id: VTR-DDR-001
title: VatReel TRL 2 review decisions
project: VatReel
doc_type: Design decision record
version: "0.1"
status: Draft
date: '2026-10-03'
author: Amish Chadha
license: CERN-OHL-S-2.0
revisions:
- version: "0.1"
  date: '2026-10-03'
  author: Amish Chadha
  change: TRL 2 review decisions made under Amish's 2026-10-03 pre-approval
---

# 0001: TRL 2 review decisions

- **Date:** 2026-10-03
- **Status:** accepted
- **Decided by:** Amish Chadha, by pre-approval: "start with the first 14 repos from the list of 29 projects. I pre-approve the batch runs along with any recommendations you come up with. I also accept any cost overruns or variations from the assumed scope cost."

## Context

The TRL 2 review (`docs/REVIEW.md`, TRL 2 section) turned the scaffold's concept, a portable hand-cranked reel set across a pit, into a formulated concept with a massing model and concept media. Formulating it raised the choices below. Under the pre-approval every recommendation is decided rather than left as "Proposed, awaiting Amish". Choices that touch safety take the conservative option and say what evidence would relax it.

## Options considered and decisions

*Table 1. Decisions made on 2026-10-03.*

| # | Item | Options | Decision |
| --- | --- | --- | --- |
| 1 | How the reel spans the pit | (a) reel shaft between end stands on opposite rims, telescoping for 1.0 to 2.5 m; (b) a static telescopic pivot tube across the pit, with the reel on two arms that swing on it | (b): only a static tube telescopes; the reel stays 0.6 m long next to the operator's rim. A turning telescopic shaft would expose a rotating, sliding joint over the pit |
| 2 | Reel axis | (a) along the rim; (b) across the pit, pointing at the operator | (b): the 0.6 m reel fits a 1.0 m wide pit, and its 1.18 m diameter lies along the pit's length (pits at least 1.9 m long) |
| 3 | Depth setting and lift | (a) a lift lever with a pawl quadrant; (b) a self-locking lead screw with a handwheel acting on a lever on the arm frame | (b), the conservative choice: a 55 kg reel and load cannot drop into a hot bath, and the depth can be set anywhere. Evidence that would relax it: a lever with a double pawl proof-loaded to 1.5 x and shown faster in trials |
| 4 | Drive | (a) one chain from crank to reel (crank height changes with depth); (b) two chains, crank to a jackshaft on the pivot line, jackshaft to reel along the arm | (b): the crank stays 1.0 m above the floor at every depth; ratio 6 to 1 |
| 5 | Holding brake | (a) friction band; (b) ratchet and pawl on the crank shaft | (b): positive, no adjustment, holds 1.5 x with large margins |
| 6 | Materials | (a) painted mild steel; (b) 304 frame, 316L for wetted parts; (c) all 316L | (b): 316L wherever liquor reaches; 304 for the frame; glass-filled PTFE bushes in the liquor, UHMW-PE above it. Coupon tests (R6) may move parts between grades |
| 7 | Carriers | (a) spring clip bars; (b) carrier bars with eye tabs and stainless snap hooks; yarn hanks looped over the bars | (b): no springs in the liquor; hides toggled through a punched hole at one edge, the usual tannery practice. Workers confirm the method with the first partner |
| 8 | Guarding | (a) guard only the crank end; (b) enclose both chains, the sprockets and the ratchet | (b), conservative: chain 1 inside the tower, chain 2 in a closed case, ratchet under a cover. R12 added. Evidence to relax: none expected |
| 9 | Hot baths | (a) one operator; (b) two people present whenever the bath is above 60 °C | (b), conservative operating rule written into the build plan's safety stops. Evidence to relax: trials showing no scald exposure at the crank position |
| 10 | Shared blocks | (a) adopt the proposed hand capstan block; (b) VatReel's own chain drive; CalRig for the proof load | (b): the capstan block assumes a fixed drum; CalRig is the first candidate for the R5 test at TRL 4 |
| 11 | Requirements | Keep R1 to R10; add a lift requirement and a guarding requirement | R11 (self-locking lift, 100 N at the handwheel, every bar above the rim) and R12 (guarding) added; pit length of 1.9 m added to the assumptions |
| 12 | First co-design partner | Tannery cluster association; worker health NGO; craft-dyeing cooperative | First candidate to approach: a worker health NGO or tannery association in the Kanpur leather cluster, India. A candidate, not an agreed partner |
| 13 | Value-engineering target | Keep USD 1,500 | Kept; `budget_usd` unchanged. Cost overruns are accepted by the pre-approval |

## Consequences

- VTR-PRC-001, VTR-REQ-001 and VTR-PRB-001 move to v0.2 with these decisions; the TRL 2 concept media are drawn from the massing model.
- The TRL 3 calculations (VTR-CAL-001) size the arm, drive, lift screw and frame; making the design constructable is recorded in VTR-DDR-002.
- No TRL 4 work (building, testing, test plans or purchasing lists) follows from this record.

> **Safety:** Items 3, 8 and 9 are safety choices and take the conservative option. The design is an open engineering reference, not certified equipment.

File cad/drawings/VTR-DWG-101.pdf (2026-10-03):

### BUILD PLAN SKETCH, PLAN NOT YET BUILT VatReel · github.com/BoujeeEnjinia1701/vatreel

FRONT VIEW
Scale 1:20; looking at the front (along +Y)

TOP VIEW
Scale 1:20; looking down (along -Z)

RIGHT VIEW
Scale 1:20; looking at the right side (along -X)

1750

660 40

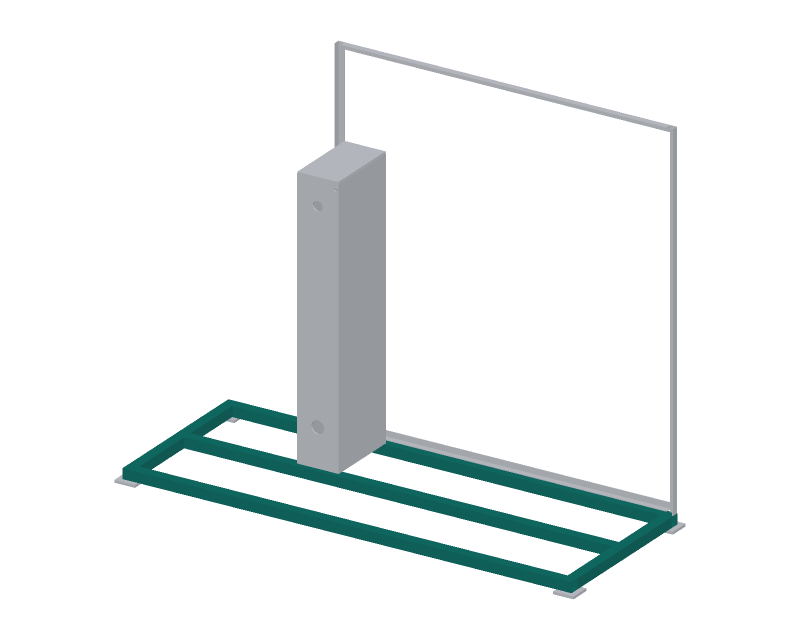
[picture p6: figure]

WHERE IT GOES
This part in colour, its neighbours in grey

HOW TO MAKE IT AND HOW IT FITS
Four rails 1750 long and two side rails 580 long, all 40 x 40 x 2 SHS. Front rail and back rail 660 apart, outside faces; mid rail 320 from front. Mid rail carries the rear tower plate; front rail the front plate.
Saw square, deburr, tack on a flat floor, check diagonals equal within 3. Weld all round each joint; cap the open rail ends with 2 mm plate. Drill 9 mm for M8: four in each rail under the tower plate tabs,
two at each brace foot on the mid rail, four for the shield posts.
Glue an 80 x 80 x 10 EPDM pad under each corner.
Fits: the tower plates stand on the front and mid rails, bolted. Check: frame flat within 3 mm when standing on its pads.
REV | DESCRIPTION | DATE | BY
P1 | Making sketch for the prototype build plan | 2026-10-03 | AC
VATREEL | github.com/BoujeeEnjinia1701/vatreel

## VatReel: near stand base frame (make 1)

DRAWING NO.
VTR-DWG-101

REV
P1

SHEET
1 of 1

SIZE

## ANSI B

SCALE
1:20

UNITS
mm
PROJECTION | DATE
2026-10-03

DRAWN
Amish Chadha

MATERIAL / NOTES
304 stainless SHS 40 x 40 x 2
Licensed CERN-OHL-S-2.0 · Design Molecule Lab · designmolecule.com | Generated from cad/src; do not edit by hand

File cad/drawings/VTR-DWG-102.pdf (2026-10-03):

### BUILD PLAN SKETCH, PLAN NOT YET BUILT VatReel · github.com/BoujeeEnjinia1701/vatreel

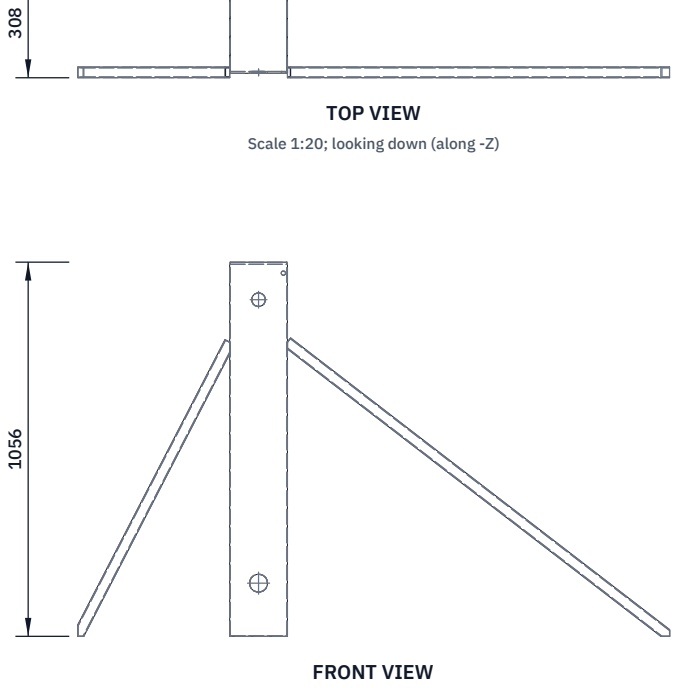
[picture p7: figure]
FRONT VIEW; TOP VIEW; Scale 1:20; looking down (along -Z)

Scale 1:20; looking at the front (along +Y)

RIGHT VIEW
Scale 1:20; looking at the right side (along -X)

1670

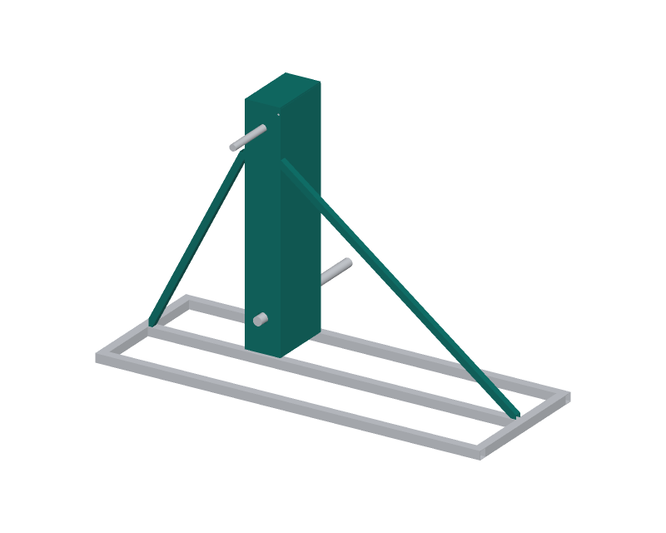
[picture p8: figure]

WHERE IT GOES
This part in colour, its neighbours in grey

HOW TO MAKE IT AND HOW IT FITS
Two plates 160 x 1050 x 5, set 290 apart (centres), front and rear. In both plates: a 50 hole 150 up from the bottom edge (jackshaft) and a 38 hole 950 up (crank shaft), both on the centre line. Drill as a pair. Rear plate only: 12 hole for the pawl pin, 70 right of and 75 above
the crank hole.
Weld 1.5 mm side sheets on both long edges and a bottom sheet, so the box is closed round the chain; weld a 6 mm top plate on.
Bend 40 mm tabs at the foot of each plate for 2 x M8 into the rails. Braces: 30 x 30 x 2 SHS from 830 up the tower side to the mid rail ends; cut the ends to sit flat; bolt M8 both ends.
Check: a 40 bar passes through both 50 holes square to the plates.
REV | DESCRIPTION | DATE | BY
P1 | Making sketch for the prototype build plan | 2026-10-03 | AC
VATREEL | github.com/BoujeeEnjinia1701/vatreel

## VatReel: bearing tower and braces (make 1)

DRAWING NO.
VTR-DWG-102

REV
P1

SHEET
1 of 1

SIZE

## ANSI B

SCALE
1:20

UNITS
mm
PROJECTION | DATE
2026-10-03

DRAWN
Amish Chadha

MATERIAL / NOTES
304 stainless plate 5, sheet 1.5, plate 6; SHS 30 x 30 x 2
Licensed CERN-OHL-S-2.0 · Design Molecule Lab · designmolecule.com | Generated from cad/src; do not edit by hand

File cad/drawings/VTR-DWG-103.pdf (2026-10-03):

### BUILD PLAN SKETCH, PLAN NOT YET BUILT VatReel · github.com/BoujeeEnjinia1701/vatreel

FRONT VIEW
Scale 1:10; looking at the front (along +Y)

TOP VIEW
Scale 1:10; looking down (along -Z)

RIGHT VIEW
Scale 1:10; looking at the right side (along -X)

40

660 40

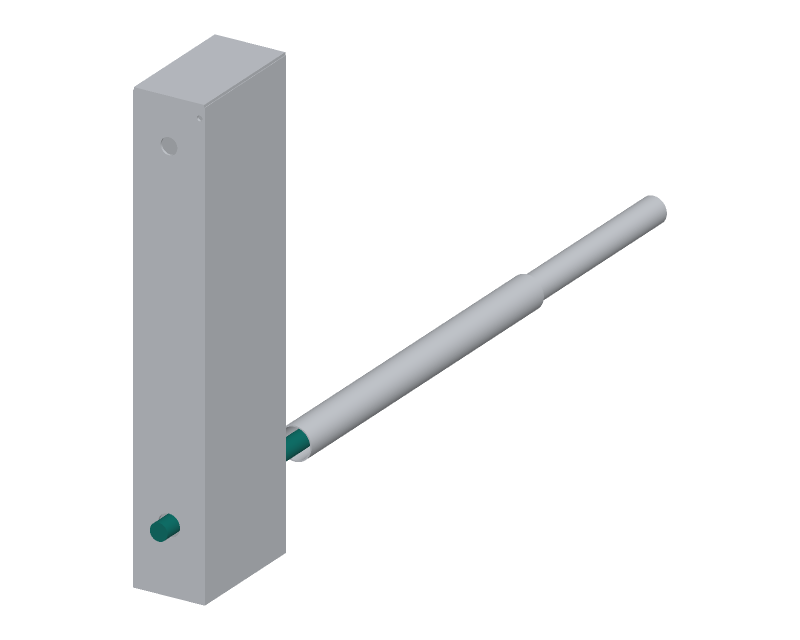
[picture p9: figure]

WHERE IT GOES
This part in colour, its neighbours in grey

HOW TO MAKE IT AND HOW IT FITS
Saw 660 long from 40 bar; chamfer both ends 1 x 45 with a file. Mark from the rear end: rear bush at 40, chain 1 sprocket at 185, front bush at 330, chain 2 sprocket at 480, torque tube bush 495 to 590, pivot tube plug 600 to 660.
Drill 6 mm cross holes for the roll pins through each sprocket hub with the sprocket on the bar (drill through hub and bar together). Polish the bush and plug lengths with fine emery; no ridges.
Fits: turns in two flanged bushes in the tower; carries the arm frame and the pivot tube plug on its front end.
Check: turns freely by hand in both bushes with the tower bolted.
REV | DESCRIPTION | DATE | BY
P1 | Making sketch for the prototype build plan | 2026-10-03 | AC
VATREEL | github.com/BoujeeEnjinia1701/vatreel

## VatReel: jackshaft (make 1)

DRAWING NO.
VTR-DWG-103

REV
P1

SHEET
1 of 1

SIZE

## ANSI B

SCALE
1:10

UNITS
mm
PROJECTION | DATE
2026-10-03

DRAWN
Amish Chadha

MATERIAL / NOTES
316 stainless round bar 40
Licensed CERN-OHL-S-2.0 · Design Molecule Lab · designmolecule.com | Generated from cad/src; do not edit by hand

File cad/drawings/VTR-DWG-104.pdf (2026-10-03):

### BUILD PLAN SKETCH, PLAN NOT YET BUILT VatReel · github.com/BoujeeEnjinia1701/vatreel

FRONT VIEW
Scale 1:5; looking at the front (along +Y)

TOP VIEW
Scale 1:5; looking down (along -Z)

RIGHT VIEW
Scale 1:5; looking at the right side (along -X)

327

512 50

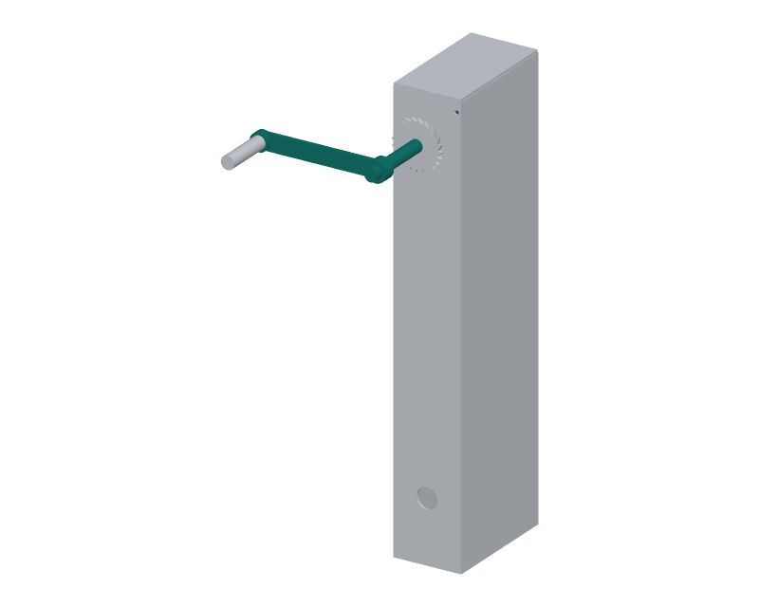
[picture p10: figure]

WHERE IT GOES
This part in colour, its neighbours in grey

HOW TO MAKE IT AND HOW IT FITS
Crank shaft: saw 30 bar 512 long; chamfer the ends.
Crank arm: 40 x 10 flat bar, holes 280 apart: 30 for the shaft,
12 for the grip pin. Weld a 50 x 30 boss (bored 30) on the shaft hole. Weld the 12 grip pin (120 long) into the outer hole, square.
Fit the crank on the shaft end with its face 20 in from the end; drill 6 through boss and shaft together; roll pin.
Ratchet goes on the same shaft 150 from the crank (sheet 105). Fits: the shaft turns in the two 30 bushes, 1000 above the rim. Check: crank arm square to the shaft; grip turns on its pin.
REV | DESCRIPTION | DATE | BY
P1 | Making sketch for the prototype build plan | 2026-10-03 | AC
VATREEL | github.com/BoujeeEnjinia1701/vatreel

## VatReel: crank shaft and crank (make 1)

DRAWING NO.
VTR-DWG-104

REV
P1

SHEET
1 of 1

SIZE

## ANSI B

SCALE
1:5

UNITS
mm
PROJECTION | DATE
2026-10-03

DRAWN
Amish Chadha

MATERIAL / NOTES
316 bar 30; 304 flat bar 40 x 10; 304 round 50 for the boss
Licensed CERN-OHL-S-2.0 · Design Molecule Lab · designmolecule.com | Generated from cad/src; do not edit by hand

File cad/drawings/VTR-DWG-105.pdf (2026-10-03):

### BUILD PLAN SKETCH, PLAN NOT YET BUILT VatReel · github.com/BoujeeEnjinia1701/vatreel

FRONT VIEW
Scale 1:5; looking at the front (along +Y)

TOP VIEW
Scale 1:5; looking down (along -Z)

RIGHT VIEW
Scale 1:5; looking at the right side (along -X)

175

78 200

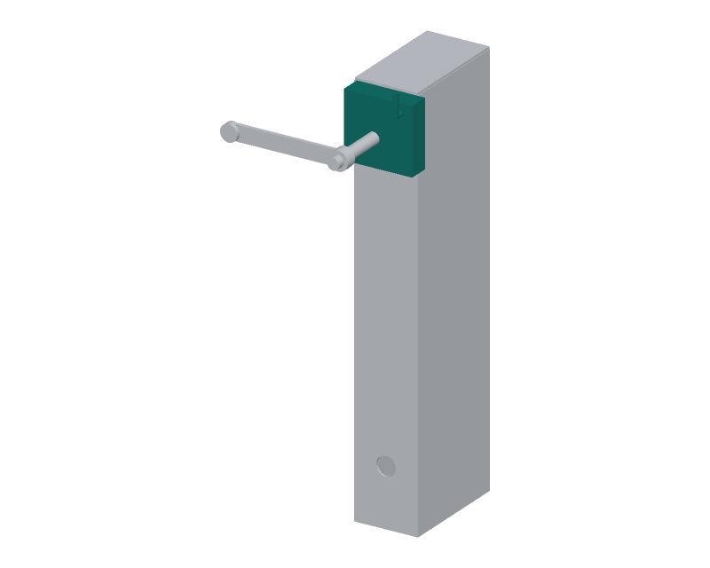
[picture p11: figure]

WHERE IT GOES
This part in colour, its neighbours in grey

HOW TO MAKE IT AND HOW IT FITS
Ratchet: 24 teeth on a 120 circle, roots on a 104 circle, from 8 plate. Mark with a printed template; saw and file each tooth: steep face toward the way the reel would run back. Weld a 44 boss, bore 30. Pawl: 8 plate, 50 long, with a 12 hole; its tip sits in a tooth root.
Pin: 12 bar through the rear plate, welded to the pawl, with a release lever outside the cover; spring holds the pawl in.
Cover: 1.5 sheet box 175 x 170 x 52 over wheel and pawl, with holes for the crank shaft and the pin; 4 M6 into the rear plate.
Fits: wheel pinned on the crank shaft just behind the rear plate. Check: crank turns one way only; lever lifts the pawl clear.
REV | DESCRIPTION | DATE | BY
P1 | Making sketch for the prototype build plan | 2026-10-03 | AC
VATREEL | github.com/BoujeeEnjinia1701/vatreel

## VatReel: ratchet, pawl and cover (make 1 set)

DRAWING NO.
VTR-DWG-105

REV
P1

SHEET
1 of 1

SIZE

## ANSI B

SCALE
1:5

UNITS
mm
PROJECTION | DATE
2026-10-03

DRAWN
Amish Chadha

MATERIAL / NOTES
304 plate 8; 304 sheet 1.5; 12 pin; spring
Licensed CERN-OHL-S-2.0 · Design Molecule Lab · designmolecule.com | Generated from cad/src; do not edit by hand

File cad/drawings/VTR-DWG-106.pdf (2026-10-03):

### BUILD PLAN SKETCH, PLAN NOT YET BUILT VatReel · github.com/BoujeeEnjinia1701/vatreel

FRONT VIEW
Scale 1:20; looking at the front (along +Y)

TOP VIEW
Scale 1:20; looking down (along -Z)

RIGHT VIEW
Scale 1:20; looking at the right side (along -X)

1320

29 1400

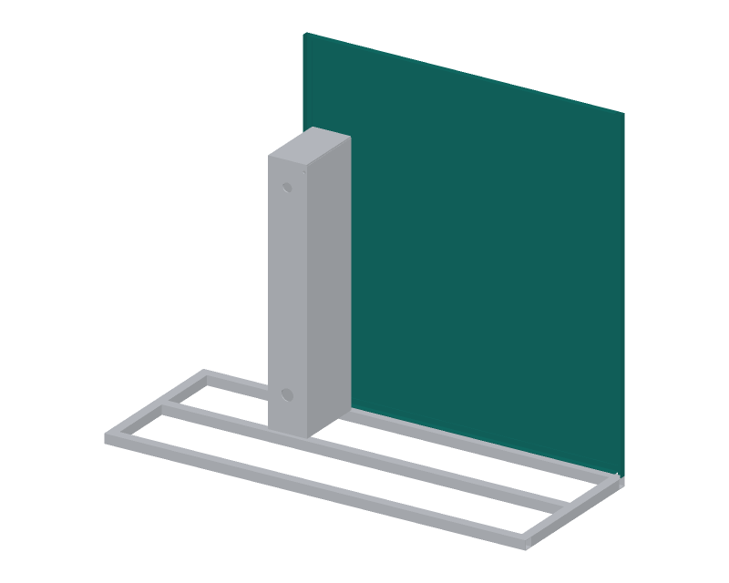
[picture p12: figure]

WHERE IT GOES
This part in colour, its neighbours in grey

HOW TO MAKE IT AND HOW IT FITS
Frame: two posts 1400 long and two cross members 1270 long of angle, mitred, welded into a rectangle 1320 x 1400 (outside).
One leg lies flat toward the pit; the other leg points back to the
tower so the frame bolts to the front tower plate.
Sheet: 4 PP 1270 x 1140 with a 52 hole for the jackshaft, centre 60 right of the left edge of the sheet and 115 up.
Drill the sheet 8 at 200 pitch round its edge, frame 6.5; M6 A4 with large washers (PP moves with heat).
Fits: posts bolt to the front rail; the frame to the tower plate. Check: no gap over 10 mm round the jackshaft or along the posts.
REV | DESCRIPTION | DATE | BY
P1 | Making sketch for the prototype build plan | 2026-10-03 | AC
VATREEL | github.com/BoujeeEnjinia1701/vatreel

## VatReel: splash shield (make 1)

DRAWING NO.
VTR-DWG-106

REV
P1

SHEET
1 of 1

SIZE

## ANSI B

SCALE
1:20

UNITS
mm
PROJECTION | DATE
2026-10-03

DRAWN
Amish Chadha

MATERIAL / NOTES
304 angle 25 x 25 x 3; 4 mm translucent polypropylene
Licensed CERN-OHL-S-2.0 · Design Molecule Lab · designmolecule.com | Generated from cad/src; do not edit by hand

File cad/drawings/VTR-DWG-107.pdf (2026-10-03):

### BUILD PLAN SKETCH, PLAN NOT YET BUILT VatReel · github.com/BoujeeEnjinia1701/vatreel

FRONT VIEW
Scale 1:5; looking at the front (along +Y)

TOP VIEW
Scale 1:5; looking down (along -Z)

RIGHT VIEW
Scale 1:5; looking at the right side (along -X)

390

315 116

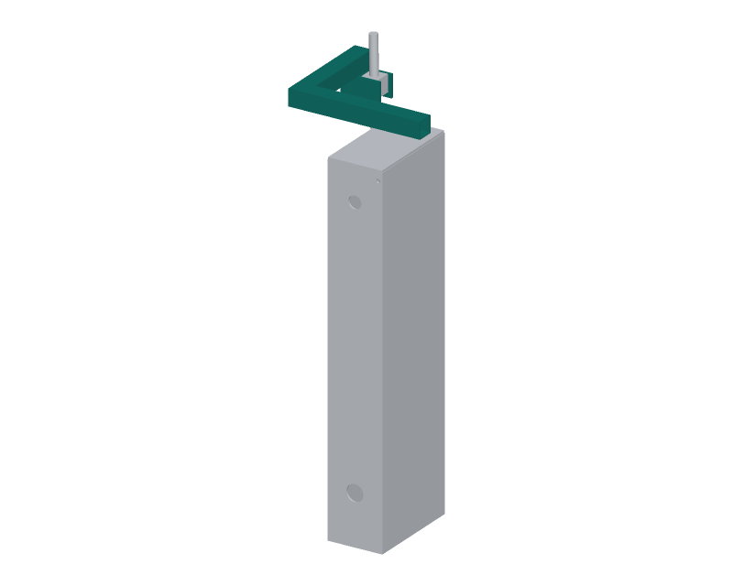
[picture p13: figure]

WHERE IT GOES
This part in colour, its neighbours in grey

HOW TO MAKE IT AND HOW IT FITS
Member 1: 390 of SHS; member 2: 265 of SHS, welded at a right angle at one end of member 1, pointing toward the pit.
Two fork plates 115 x 66 x 8 under the end of member 2, 50 apart inside, each with a 16.5 hole 26 up from the bottom, in line. Member 1 lies on the tower top plate: two 10.5 holes 100 apart. Weld all round; full fillets on the fork plates (screw load 3.8 kN). Fits: bolts on the tower top with 2 M10; the upper trunnion block hangs between the fork plates on two 16 pins.
Check: the two fork holes line up with a 16 bar through both.
REV | DESCRIPTION | DATE | BY
P1 | Making sketch for the prototype build plan | 2026-10-03 | AC
VATREEL | github.com/BoujeeEnjinia1701/vatreel

## VatReel: lift screw bracket (make 1)

DRAWING NO.
VTR-DWG-107

REV
P1

SHEET
1 of 1

SIZE

## ANSI B

SCALE
1:5

UNITS
mm
PROJECTION | DATE
2026-10-03

DRAWN
Amish Chadha

MATERIAL / NOTES
304 SHS 50 x 50 x 3; 304 plate 8
Licensed CERN-OHL-S-2.0 · Design Molecule Lab · designmolecule.com | Generated from cad/src; do not edit by hand

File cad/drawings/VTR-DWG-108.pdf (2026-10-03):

### BUILD PLAN SKETCH, PLAN NOT YET BUILT VatReel · github.com/BoujeeEnjinia1701/vatreel

FRONT VIEW
Scale 1:10; looking at the front (along +Y)

TOP VIEW
Scale 1:10; looking down (along -Z)

RIGHT VIEW
Scale 1:10; looking at the right side (along -X)

66

50 845

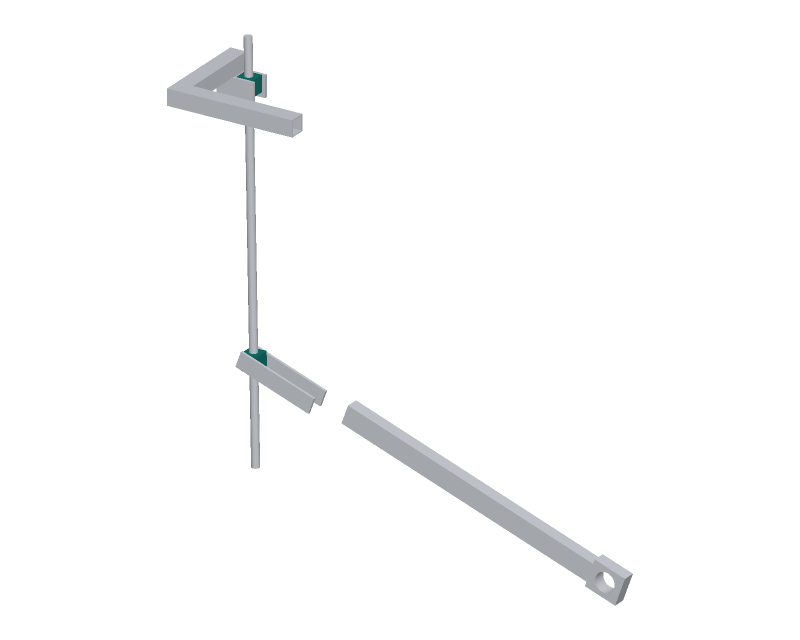
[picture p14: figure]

WHERE IT GOES
This part in colour, its neighbours in grey

HOW TO MAKE IT AND HOW IT FITS
Two 50 cubes. Drill 25 through both on one axis (the screw axis). Upper block: counterbore 47 x 12 on top for the 51105 thrust bearing. Nut block: counterbore for the bronze flanged nut; 2 M6 hold it. Both: drill and tap two opposite faces M16, 25 deep, on the centre, square to the screw hole; screw in 16 pins with a shoulder.
Fits: upper block hangs in the bracket forks; nut block sits between the two lever plates on the arm frame. Both pivot on their pins. Check: each block swings freely on its pins without play over 0.5.
REV | DESCRIPTION | DATE | BY
P1 | Making sketch for the prototype build plan | 2026-10-03 | AC
VATREEL | github.com/BoujeeEnjinia1701/vatreel

## VatReel: trunnion blocks (make 2)

DRAWING NO.
VTR-DWG-108

REV
P1

SHEET
1 of 1

SIZE

## ANSI B

SCALE
1:10

UNITS
mm
PROJECTION | DATE
2026-10-03

DRAWN
Amish Chadha

MATERIAL / NOTES
316 block 50 x 50 x 50; 16 pins; bronze nut; thrust bearing
Licensed CERN-OHL-S-2.0 · Design Molecule Lab · designmolecule.com | Generated from cad/src; do not edit by hand

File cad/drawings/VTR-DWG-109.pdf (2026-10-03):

### BUILD PLAN SKETCH, PLAN NOT YET BUILT VatReel · github.com/BoujeeEnjinia1701/vatreel

FRONT VIEW
Scale 1:10; looking at the front (along +Y)

TOP VIEW
Scale 1:10; looking down (along -Z)

RIGHT VIEW
Scale 1:10; looking at the right side (along -X)

60

1205 60

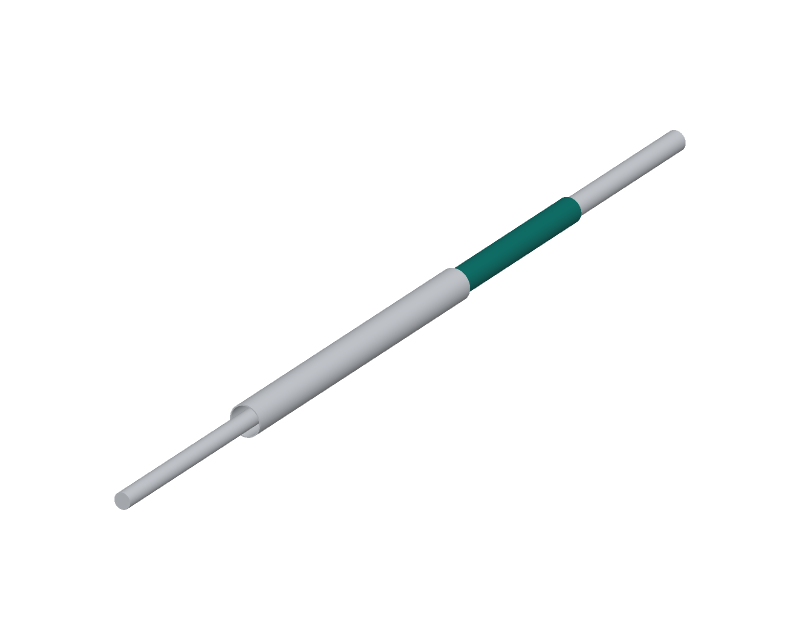
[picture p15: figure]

WHERE IT GOES
This part in colour, its neighbours in grey

HOW TO MAKE IT AND HOW IT FITS
Saw 1205 long; deburr inside and out.
Plug: a 304 ring 49 outside, 70 long, holding a UHMW bush bored 40; push it into the near end flush and plug weld through three 8 holes. At the far end drill 10 cross holes at 100 pitch for the extension pin, the first 30 from the end, five holes in all.
Slide on the 68 inner collar before the arm frame (sheet 112). Fits: the plug slides onto the jackshaft tip; the arm frame's far
bush turns on this tube; the extension slides inside it.
Check: the extension tube slides in by hand its whole length.
REV | DESCRIPTION | DATE | BY
P1 | Making sketch for the prototype build plan | 2026-10-03 | AC
VATREEL | github.com/BoujeeEnjinia1701/vatreel

## VatReel: pivot tube with plug (make 1)

DRAWING NO.
VTR-DWG-109

REV
P1

SHEET
1 of 1

SIZE

## ANSI B

SCALE
1:10

UNITS
mm
PROJECTION | DATE
2026-10-03

DRAWN
Amish Chadha

MATERIAL / NOTES
304 pipe 60.3 x 5.54 (2 in schedule 80); UHMW-PE bush
Licensed CERN-OHL-S-2.0 · Design Molecule Lab · designmolecule.com | Generated from cad/src; do not edit by hand

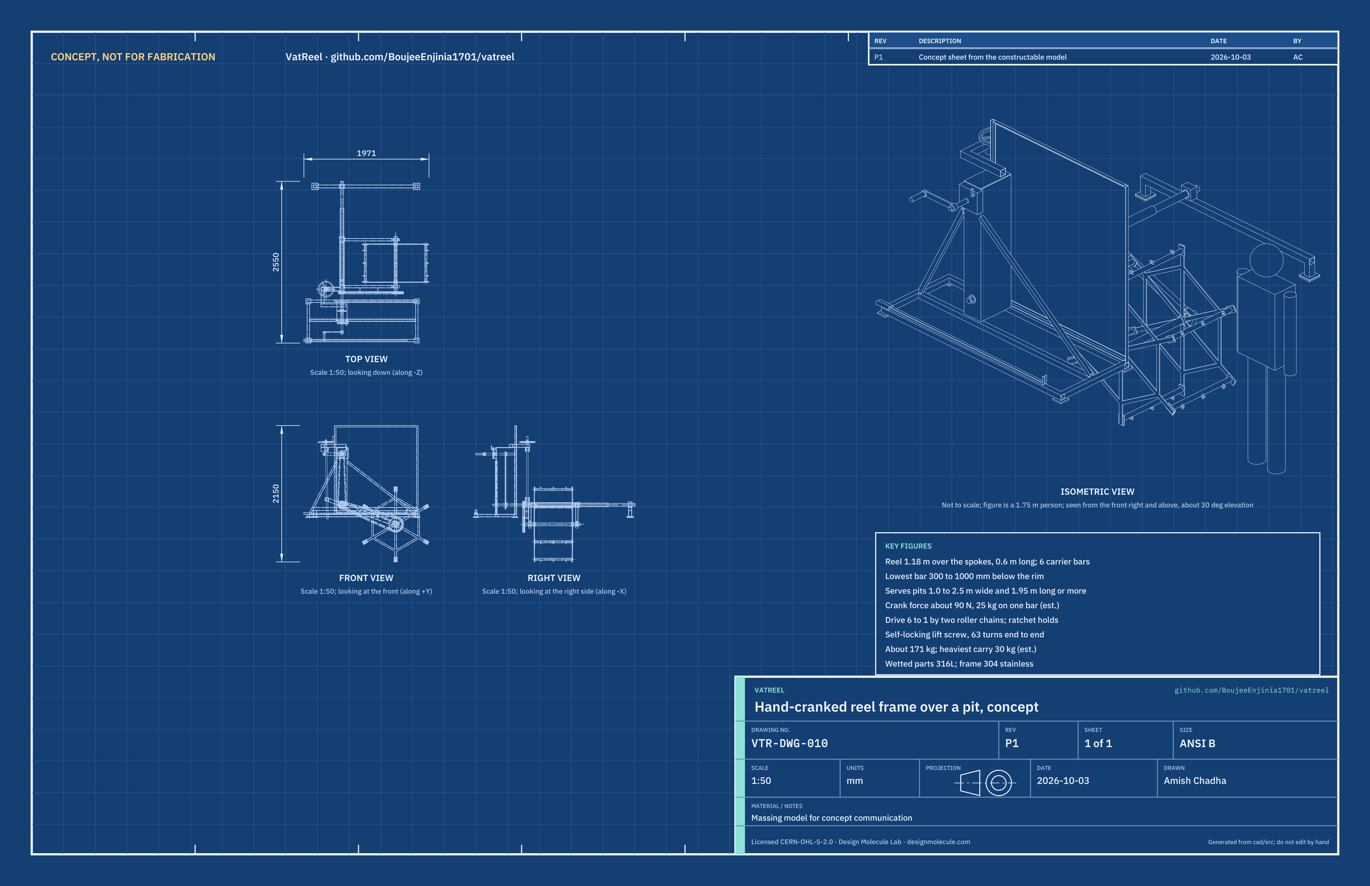
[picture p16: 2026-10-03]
media/concept-blueprint.png

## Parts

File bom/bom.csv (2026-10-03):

item | qty | spec | supplier | unit_cost_usd | make_buy | notes
1 Near stand base frame | 1 | Rectangle 1750 x 660 mm of 40 x 40 x 2 mm SHS with a mid rail under the rear tower plate; 304 stainless; about 15 kg | Local stainless stockist (sections) | 68.00 | make | VTR-CAL-001 mass x USD 4.50/kg plus cutting discs
2 Bearing tower and braces | 1 | Two 5 mm plates 160 x 1050 mm (holes 50 mm at 200 mm and 38 mm at 1000 mm above the rim), 1.5 mm side sheets and bottom sheet, 6 mm top plate; two 30 x 30 x 2 mm SHS braces bolted to the base mid rail; 304 stainless; about 23.2 kg plus 3.7 kg of braces | Local stainless stockist (plate and sheet) | 125.00 | make | Encloses chain 1; mass x USD 4.50/kg
3 Jackshaft | 1 | 40 mm round bar 660 mm long, 316 stainless, cross-drilled for two 6 mm sprocket pins; about 6.6 kg | Local stainless stockist (bar) | 45.00 | make | Bar x USD 6.50/kg plus drilling
4 Crank shaft crank and grip | 1 | 30 mm 316 bar 512 mm long; crank arm 40 x 10 mm 304 flat bar 280 mm between centres with a 50 mm boss; turning grip 32 mm on a 12 mm pin, 120 mm long | Local stainless stockist; hardware store (grip) | 34.00 | make | Grip bought
5 Ratchet pawl and cover | 1 | Ratchet wheel 120 mm over the tips, 24 teeth, cut from 8 mm 304 plate with a 44 mm boss; pawl 8 mm plate on a 12 mm pin through the rear tower plate with a release lever outside the cover; 1.5 mm sheet cover; compression spring | Local stainless stockist; hardware store (spring) | 22.00 | make | Teeth cut and filed by hand or plasma cut
6 Splash shield | 1 | Frame of 25 x 25 x 3 mm 304 angle 1320 x 1400 mm; 4 mm translucent polypropylene sheet 1270 x 1140 mm; 8 M6 A4 bolts | Local stainless stockist; plastics supplier (PP sheet) | 70.00 | make | PP sheet about USD 40; frame about 6 kg x USD 4.50/kg
7 Lift screw bracket | 1 | Two 50 x 50 x 3 mm 304 SHS members 390 and 265 mm welded in an L; two 8 mm fork plates 115 x 66 mm; 2 M10 bolts to the tower top; about 3.9 kg | Local stainless stockist (sections) | 20.00 | make
8 Lift screw trunnions and handwheel | 1 | Tr24 x 5 single-start threaded rod 316, 1250 mm (cut from 2 m); bronze Tr24 x 5 flanged nut in a 50 x 50 x 50 mm 316 trunnion block; upper 316 trunnion block with a 51105 stainless thrust ball bearing; 250 mm handwheel with spinner; trunnion pins 16 mm | Power transmission supplier (screw and nut); bearing shop; hardware store (handwheel) | 130.00 | buy | Self-locking; 63 turns end to end (VTR-CAL-001)
9 Bushes | 1 | Four flanged UHMW-PE bushes in the tower (two 40 mm bore and two 30 mm bore); torque tube bushes in UHMW-PE (40 x 70 x 95 mm and 60.3 x 70 x 60 mm); pivot tube plug bush 40 x 49 x 70 mm; two split glass-filled PTFE axle bushes 48.3 x 60 x 40 mm | Bearing shop or plastics supplier | 63.00 | buy | PTFE in the hot liquor; UHMW-PE only above it (VTR-DDR-002)
10 Sprockets | 1 | ISO 606 08B-1 plate sprockets with hubs: 15 teeth bored 30 (crank) and 30 teeth bored 40 (jackshaft), zinc-plated steel, inside the tower; 17 teeth bored 40 and 51 teeth bored 48.3, 304 stainless, on the arm; each pinned with a 6 mm roll pin | Bearing and power transmission shop | 97.00 | buy | Stainless pair about USD 65; plated pair about USD 32
11 Roller chains | 1 | ISO 606 08B-1: chain 1 zinc-plated steel about 1.9 m (inside the tower); chain 2 304 stainless about 2.3 m (on the arm); with connecting links | Bearing and power transmission shop | 62.00 | buy | Chain 2 runs in the liquor at the deepest settings (wear to confirm when parts are bought)
12 Pivot tube with plug and collars | 1 | 60.3 x 5.54 mm (2 in schedule 80) 304 pipe 1205 mm; welded-in end plug ring with UHMW-PE bush 40 mm bore; two split collars (68 mm inside the torque tube and 90 mm outside); 10 mm cross holes at 100 mm pitch toward the far end for the extension pin; about 9.1 kg | Local stainless stockist (pipe); bearing shop (collars) | 74.00 | make
13 Extension tube | 1 | 48.3 x 3.68 mm 304 pipe 1550 mm with 10 mm cross holes at 100 mm pitch; one 10 mm lynch pin with lanyard; about 6.3 kg | Local stainless stockist (pipe) | 33.00 | make | Used for pits wider than about 1.22 m
14 Far stand with clamp and sleeve | 1 | Crossbeam 50 x 50 x 3 mm 304 SHS 1650 mm; two legs 94 mm of the same SHS on 100 x 100 x 6 mm foot plates; clamp block 90 x 60 x 90 mm split on the tube centre line with 2 M10 bolts; split sleeve 48.3 to 60.3 mm in two halves; about 12.4 kg | Local stainless stockist | 60.00 | make
15 Rubber pads | 6 | EPDM pads 80 x 80 x 10 mm (four under the near stand) and 100 x 100 x 10 mm (two under the far stand) | Hardware store | 3.00 | buy
16 Arm frame | 1 | Torque tube 76.1 x 3 mm 316L 845 mm; near arm and far arm 60 x 40 x 3 mm 316L rectangular tube 812 mm; near split bearing housing 100 x 90 x 40 mm with a bolted cap; far open saddle 100 x 77 x 40 mm with a keeper; two 8 mm lever plates 280 x 50 mm; about 17.2 kg | Local stainless stockist (316L tube and plate) | 105.00 | make | Mass x USD 6.50/kg plus 316L filler
17 Chain 2 guard | 1 | Closed case of 1.5 mm 316 sheet: two side plates (hull of 112 and 250 mm circles 900 mm apart) and a 34 mm rim strip bent round by hand; two 16 mm spacer tubes 58 mm to the near arm; about 5.7 kg | Local stainless stockist (sheet) | 38.00 | make
18 Reel | 1 | Axle 48.3 x 3.68 mm 316L pipe 900 mm; two spiders, each six 30 x 6 mm 316L flat bar spokes 560 mm on a 60.3 mm hub sleeve 40 mm long, with six 25 x 6 mm ties at 420 mm radius; about 19.4 kg | Local stainless stockist (316L pipe and flat bar) | 136.00 | make | Mass x USD 6.50/kg plus 316L filler and a welding jig
19 Carrier bars with eyes and snap hooks | 1 | Six 33.7 x 2 mm 316L tubes 582 mm with 75 x 50 x 6 mm end plates (2 x M10 A4 each end) and three 6 mm eye tabs; eighteen 316 snap hooks 60 mm; about 8.1 kg | Local stainless stockist; chandlery or hardware store (snap hooks) | 110.00 | make | Snap hooks about USD 2.50 each
20 Loading hooks | 2 | 12 mm 316 rod 1500 mm with a 60 mm hook, on a 28 mm polypropylene handle 120 mm | Local stainless stockist | 12.00 | make | Kept on the base frame
21 Fasteners and pins | 1 | A4 stainless M6 to M12 bolts, nuts and washers; 6 mm roll pins; R-clips and lanyards | Fastener supplier | 45.00 | buy | Not modeled
22 Assembly bar | 1 | 33.7 x 3.2 mm galvanized steel pipe 3.6 m, passed through the reel axle so two people on opposite rims can carry the reel | Local steel stockist | 18.00 | buy | Tool; not modeled
23 Welding and finishing consumables | 1 | 316L filler wire or rods, cutting and flap discs, pickling paste | Welding supplier | 40.00 | buy | Not modeled

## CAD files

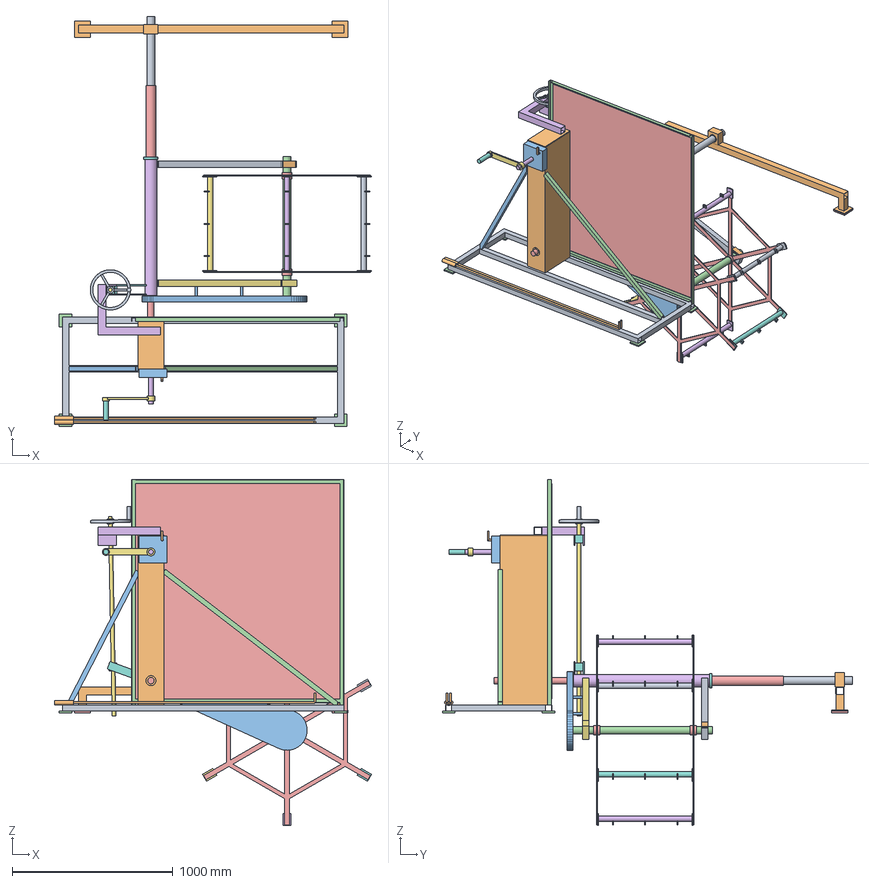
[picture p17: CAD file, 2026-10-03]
cad/step/vatreel-assembly.step
1971.3 x 2550.0 x 2150.3 mm

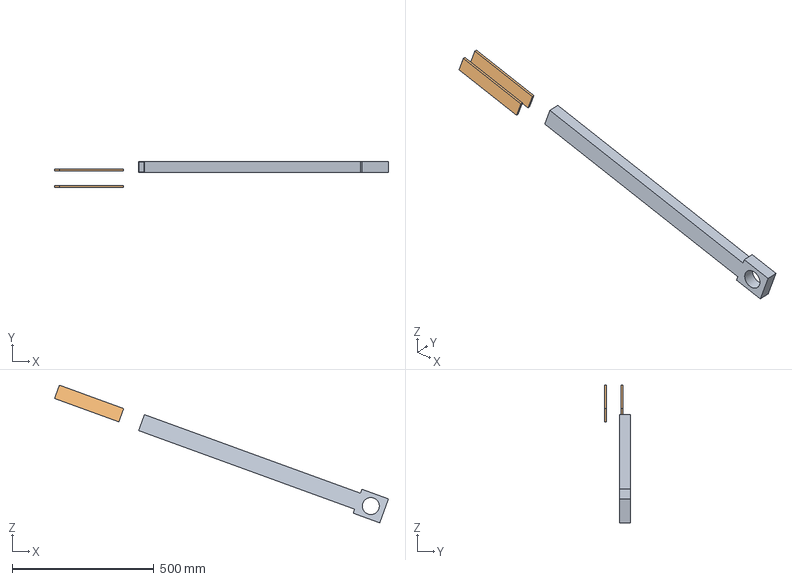
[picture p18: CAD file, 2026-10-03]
cad/step/near-arm.step
1179.8 x 93.0 x 486.5 mm

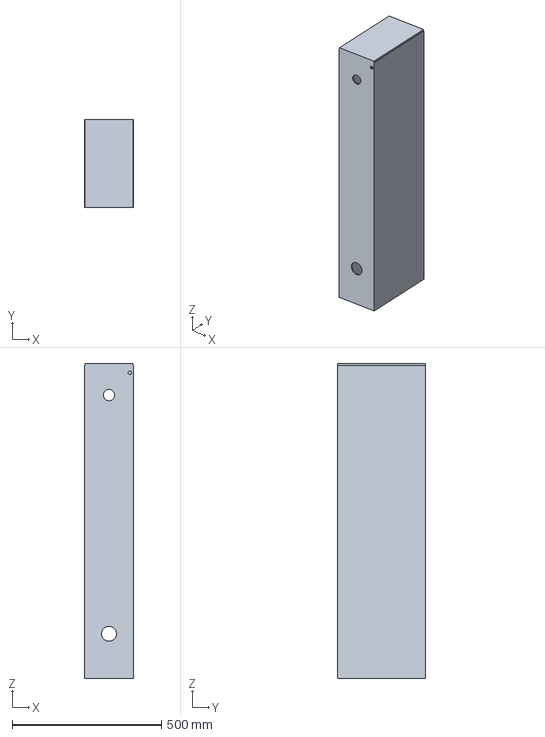
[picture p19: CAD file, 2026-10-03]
cad/step/bearing-tower.step
163.0 x 295.0 x 1056.0 mm

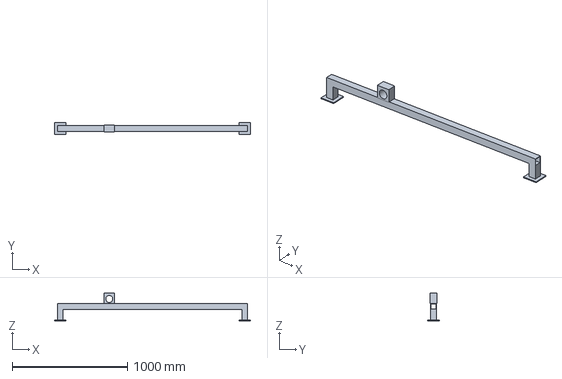
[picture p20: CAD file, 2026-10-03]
cad/step/far-stand.step
1700.0 x 100.0 x 240.0 mm

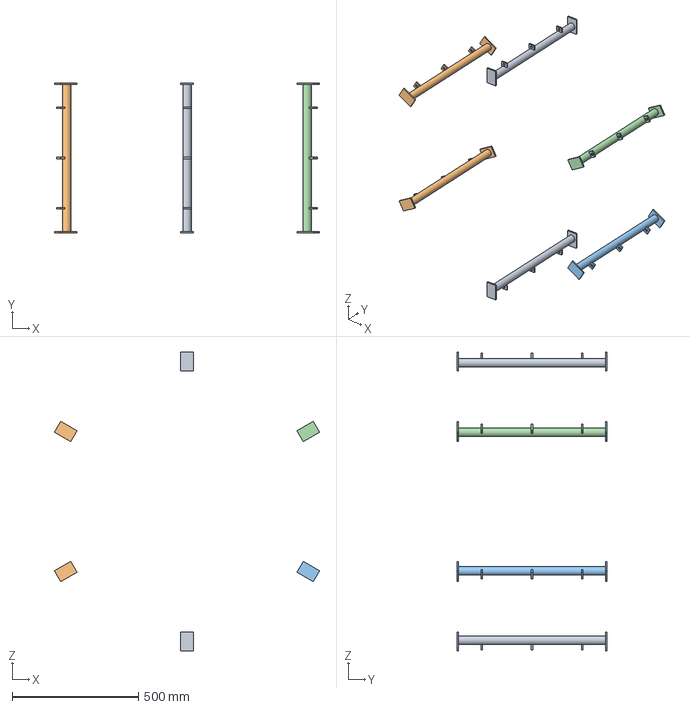
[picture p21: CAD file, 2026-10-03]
cad/step/carrier-bars.step
1051.2 x 594.0 x 1185.0 mm

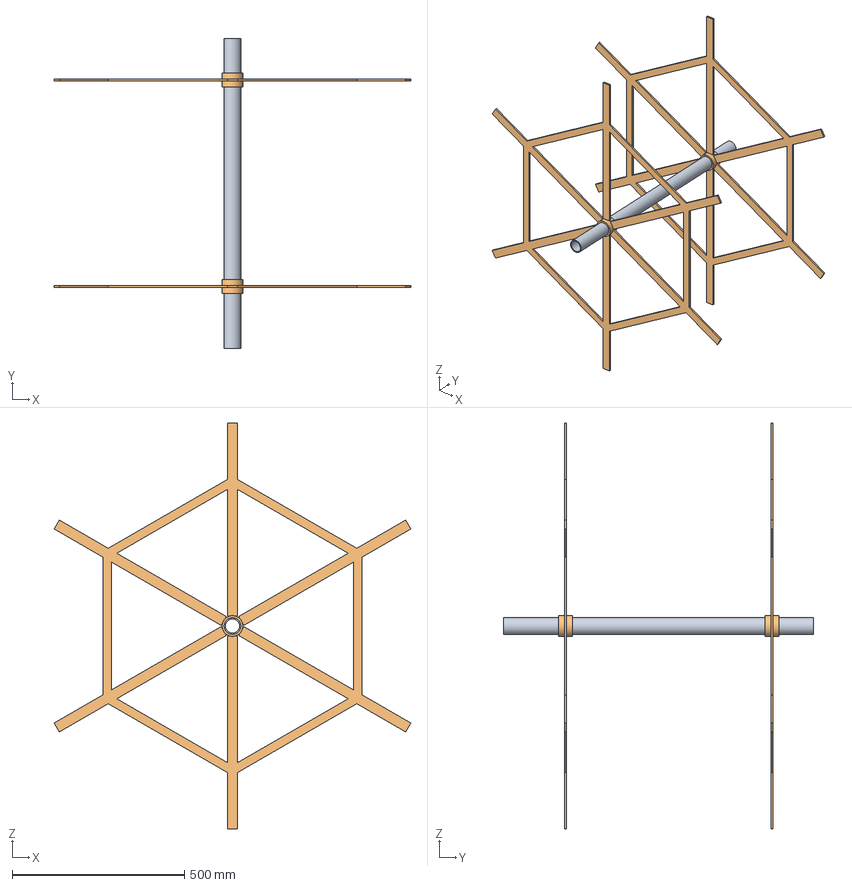
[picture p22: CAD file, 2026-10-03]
cad/step/reel.step
1036.9 x 900.0 x 1180.0 mm

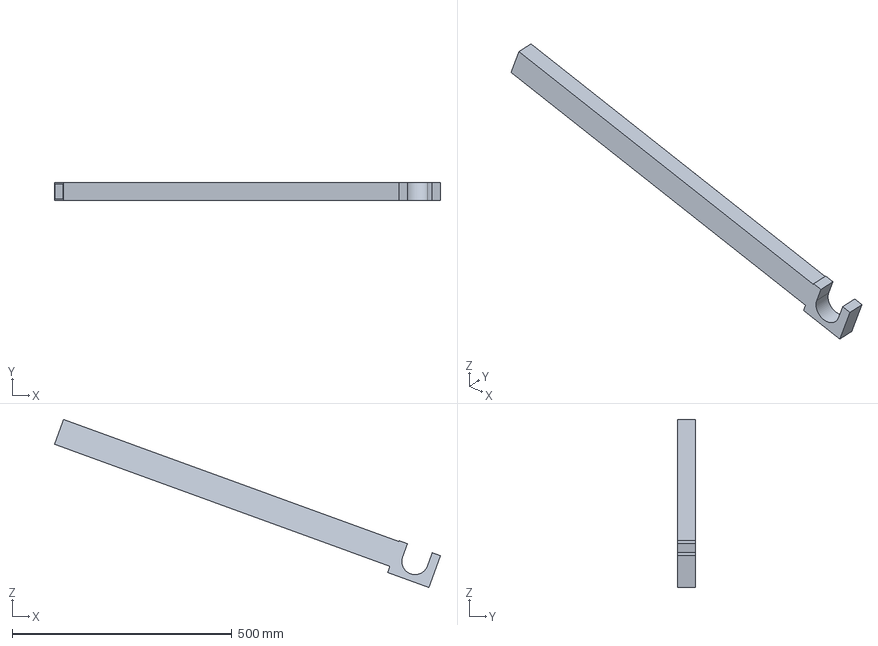
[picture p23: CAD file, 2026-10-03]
cad/step/far-arm.step
878.2 x 40.0 x 382.4 mm

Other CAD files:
cad/stl/bearing-tower.stl
cad/stl/carrier-bars.stl
cad/stl/far-arm.stl
cad/stl/far-stand.stl
cad/stl/near-arm.stl
cad/stl/reel.stl

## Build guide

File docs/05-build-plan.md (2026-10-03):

---
doc_id: VTR-BLD-001
title: VatReel prototype build plan
project: VatReel
doc_type: Build plan
version: "0.1"
status: Draft
date: '2026-10-03'
author: Amish Chadha
license: CERN-OHL-S-2.0
revisions:
- version: "0.1"
  date: '2026-10-03'
  author: Amish Chadha
  change: First build plan; design made constructable (VTR-DDR-002)
---

# VatReel prototype build plan

**Plan, not yet built.** How to build the first proof-of-concept prototype, component by component. Building and testing to it is TRL 4 work. Decisions are kept in the design decisions register ([docs/06-design-decisions.md](06-design-decisions.md)), not here.

## 1. What you are building

Figure 1. Every component, pulled apart and numbered in build order

*Figure 1. Every component pulled apart and numbered in build order.*

The prototype is a hand-cranked reel on a stainless frame that sits across a tannery pit or dye vat. A near stand on the operator's rim carries the crank, the drive and a splash shield; a pivot tube runs across the pit to a far stand on the opposite rim; two arms swing on the pivot tube and carry a reel with six carrier bars down into the liquor; a handwheel on a lift screw sets how deep the reel goes. Figure 1 shows the 19 groups of parts in the order you make or fit them. The work is sawing, drilling and TIG or stick welding stainless tube, bar, plate and sheet; cutting a polypropylene sheet; bending a sheet strip by hand; and fitting bought parts (chains, sprockets, bushes, the lift screw and nut, a handwheel, snap hooks). There is no casting and no lathe work. The parts cost about USD 1,437 from the bill of materials.

> **Safety:** VatReel is moving machinery used beside an open pit of corrosive and, for dyeing, hot liquor. Its build involves welding stainless steel (fume with chromium and nickel: weld outdoors or with extraction), grinding, lifts of up to 30 kg by two people over a pit edge, and a 55 kg reel and load hanging over the pit. Work only from the rims; never stand on boards or the frame over the pit. Fit and test over an empty pit or a water-filled tank before any liquor; section 6 lists the points where work stops.

## 2. What changed to make it buildable

The concept showed what VatReel does; some of its parts could not be made or fitted as drawn. Each change keeps what VatReel does and is recorded in decision record VTR-DDR-002.

*Table 1. Changes from the concept.*

| Component | The concept had | The buildable design has | Why |
| --- | --- | --- | --- |
| Arm frame | Two arms joined by a thin tie tube | Both arms welded to a torque tube round the pivot line (Figure 19) | The tie would have bent at about 280 MPa; the tube twists at 29 MPa |
| Sprockets | 12 teeth on 30 and 40 mm shafts | 15/30 and 17/51 teeth, still 6 to 1 | A 12-tooth sprocket cannot be bored that large |
| Chain 2 guard | A flat plate | A closed case round the chain (Figure 20) | No open edges near the chain |
| Bearing tower | Open bottom, ratchet exposed | Bottom sheet; ratchet cover with the release lever outside (Figure 8) | Close the chain box and the pawl |
| Far bearing | A bolted split block | An open saddle with a keeper (Figure 23) | It is 0.9 m into the pit; the reel drops in from above |
| Pivot tube support | A bracket round the sprocket | A plug riding on the jackshaft tip (Figure 6) | No bracket can pass the sprocket and the arm |
| Pivot tube reach | One telescopic tube | Pivot tube plus a pinned extension and a clamped far stand (Figure 17) | Spans 1.0 to 2.52 m |
| Splash shield | 1.12 m wide from 260 mm up | 1.32 m wide from 60 mm up, hole for the jackshaft (Figure 11) | Every sight line from the reel to the eye is blocked |
| Base frame | 1.55 m long | 1.75 m long | Carries the wider shield |
| Tower braces | Welded on | Bolted on, lowered | Tower 23.2 kg to carry; clears the ratchet cover |
| Reel | Spokes on the axle, bars welded | Spokes on hub sleeves with hexagon ties; bars bolted with end plates (Figures 21 and 25) | Jig-welded square; bars replaceable |
| Reel fitting | Not worked out | An assembly bar through the hollow axle, carried by two people on opposite rims | No one reaches over the pit |

## 3. Making the components

Make and check each component before the step that needs it. Sizes are in millimetres. "Near" is the operator's rim; "far" is the opposite rim; "along the pit" is the direction the reel turns in. Workshop tolerance is 1 mm unless a step says otherwise. Weld stainless with 316L filler (TIG, or stick with 316L electrodes), and pickle the welds of every part that goes into the liquor. Mark every part with its name in paint marker as you make it.

### 3.1 Near stand base frame

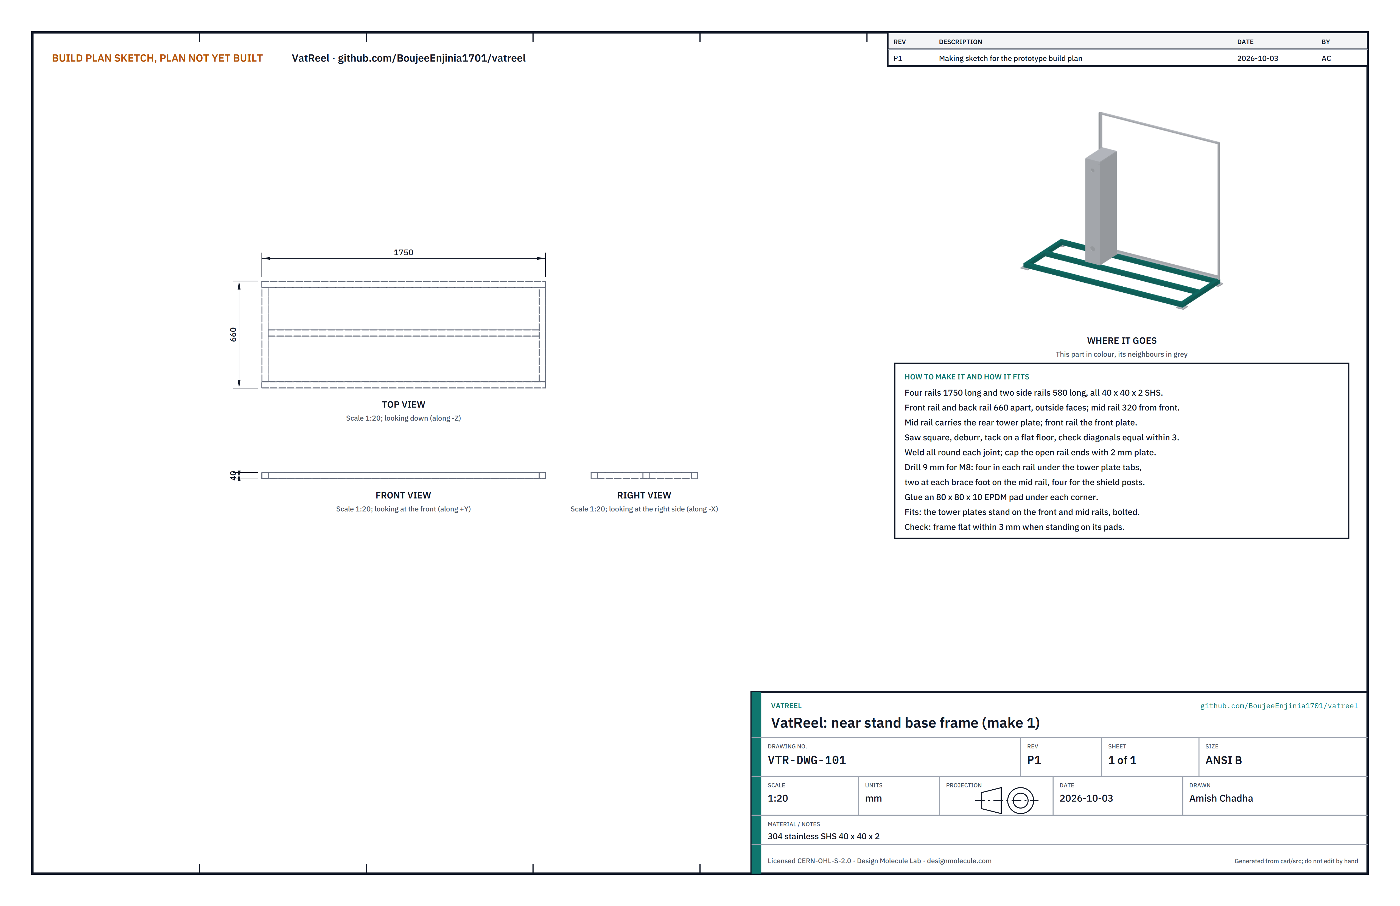
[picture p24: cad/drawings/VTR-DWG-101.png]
Figure 2. Making sketch of the base frame


*Figure 2. Base frame making sketch (VTR-DWG-101).*

**What it is and what it is made from.** The rectangle that sits on the operator's rim and carries the tower and shield. 304 stainless square tube 40 x 40 x 2; four EPDM pads 80 x 80 x 10.

**How to make it.**

1. Saw three rails 1,750 long (front, mid and back) and two side rails 580 long; deburr.
2. Lay them out on a flat floor: front and back rails 660 apart outside, the mid rail 320 behind the front rail's centre line, side rails at the ends. Check the diagonals are equal within 3.
3. Tack, recheck, then weld all round each joint. Cap the open ends with 2 mm plate.
4. Drill 9 mm holes for M8: two under each tower plate tab on the front and mid rails, two at each brace foot on the mid rail, two under each shield post on the front rail.
5. Glue a pad under each corner.

**How it fits the parts next to it.** The front tower plate stands on the front rail and the rear plate on the mid rail, each with two M8 bolts (Figure 3). The shield posts bolt to the front rail.

**Check before moving on.** The frame stands flat on its pads within 3 mm.

### 3.2 Bearing tower and braces

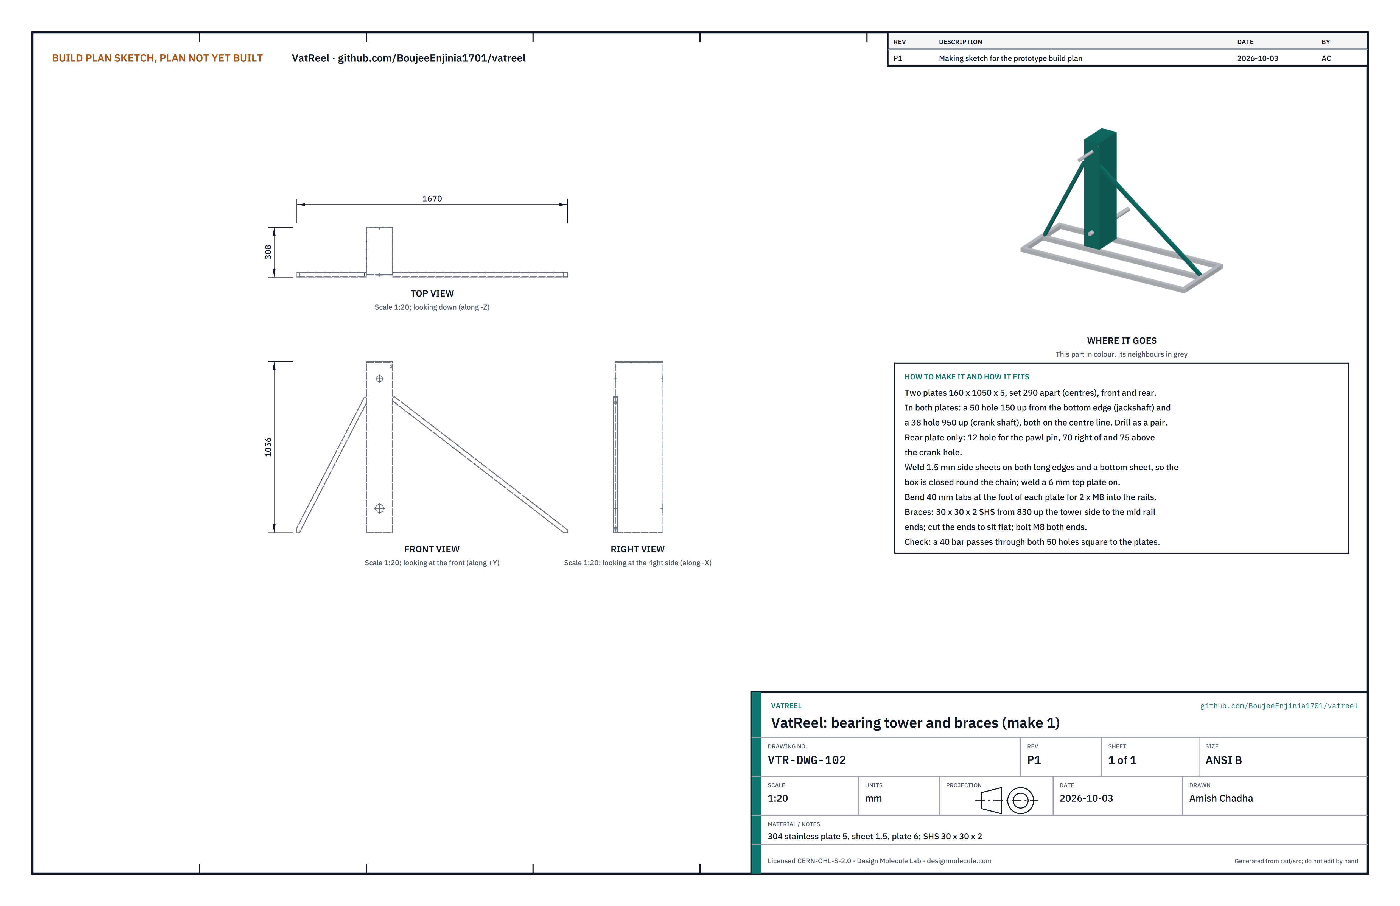
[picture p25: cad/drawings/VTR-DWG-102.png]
Figure 3. Making sketch of the bearing tower


*Figure 3. Bearing tower making sketch (VTR-DWG-102).*

**What it is and what it is made from.** A closed box that carries both shafts in bushes and encloses chain 1. Two 304 plates 160 x 1,050 x 5; 1.5 mm side sheets and bottom sheet; a 6 mm top plate; two 30 x 30 x 2 braces.

**How to make it.**

1. Cut the two plates; clamp them together and drill as a pair: a 50 hole on the centre line 150 above the bottom edge (jackshaft, 200 above the rim when standing) and a 38 hole 950 above it (crank shaft, 1,000 above the rim).
2. Rear plate only: a 12 hole for the pawl pin, 70 to the right of and 75 above the crank hole.
3. Bend a 40 mm tab at the foot of each plate with two 9 mm holes matching the rails.
4. Stand the plates 290 apart (centres) on a flat table; weld the side sheets along both long edges and the bottom sheet between them, then the top plate.
5. Braces: saw two lengths of 30 x 30 x 2 to run from 830 up each tower side down to the mid rail end; cut the ends to sit flat; drill both ends 9 mm.

**How it fits the parts next to it.**

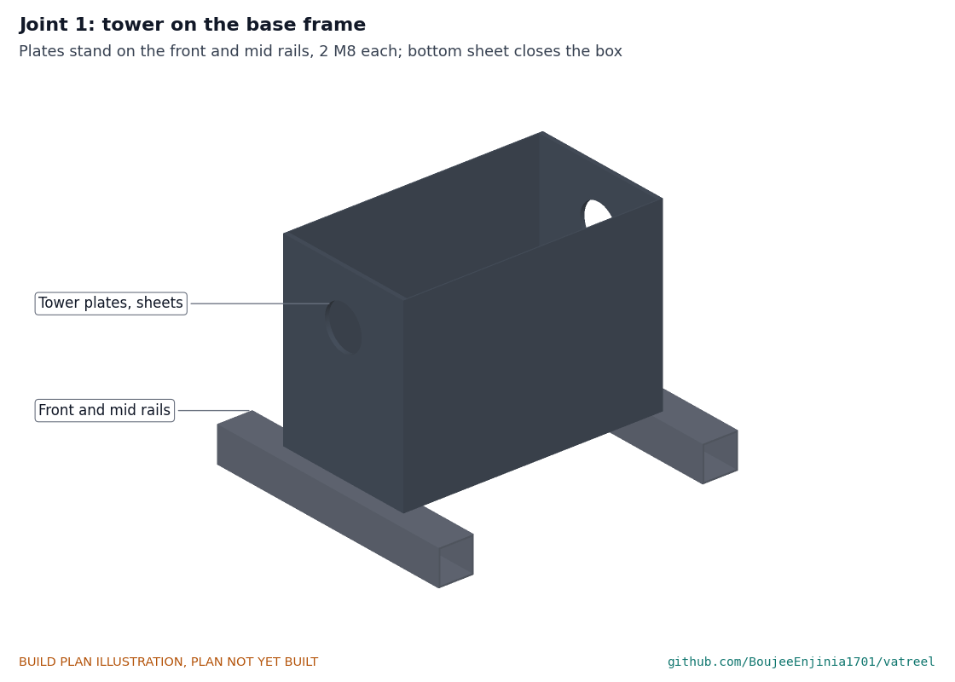
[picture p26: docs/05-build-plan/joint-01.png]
Figure 4. Joint 1: tower on the base frame


*Figure 4. Joint 1. The plates stand on the front and mid rails, two M8 each; the bottom sheet closes the box.*

**Check before moving on.** A straight 40 bar passes through both 50 holes, square to the plates.

### 3.3 Jackshaft

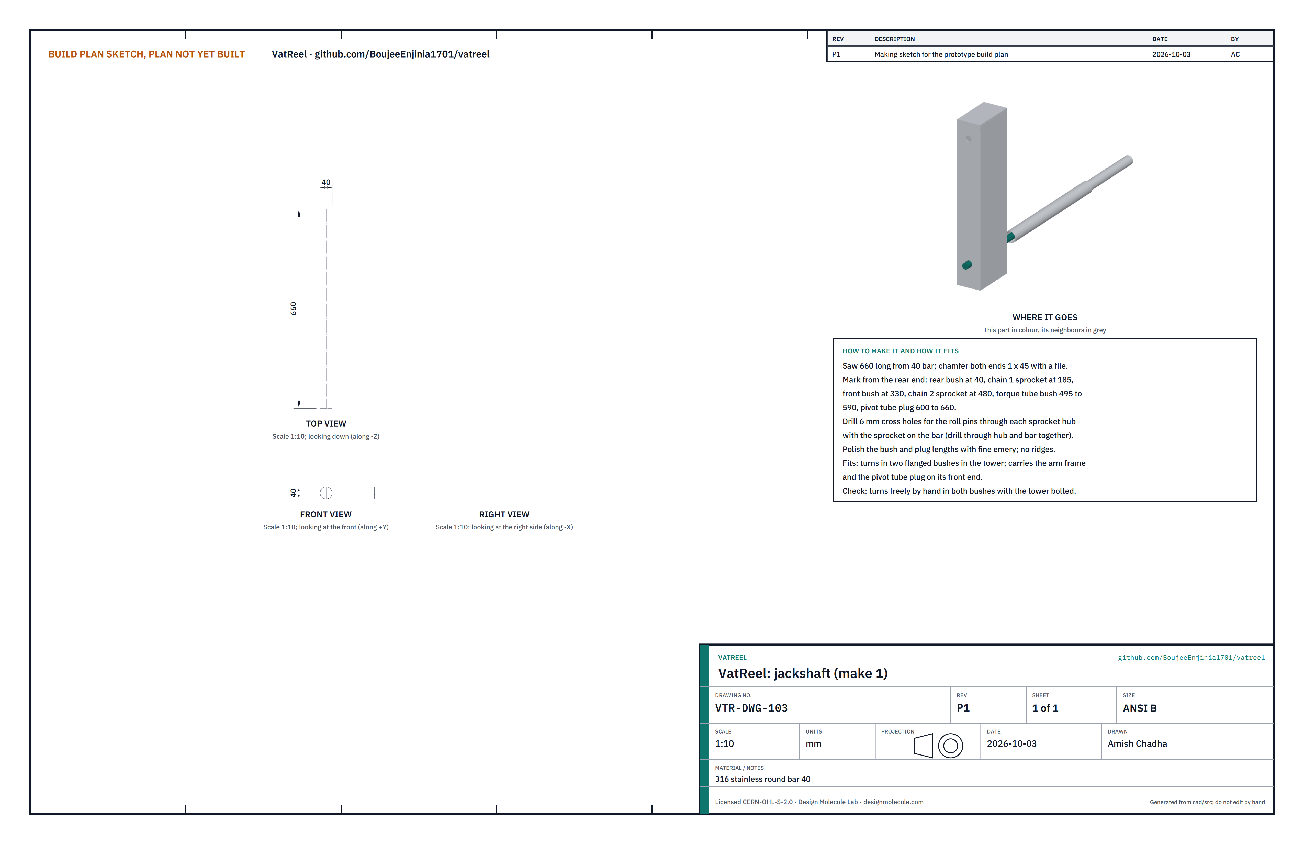
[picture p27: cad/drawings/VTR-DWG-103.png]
Figure 5. Making sketch of the jackshaft


*Figure 5. Jackshaft making sketch (VTR-DWG-103).*

**What it is and what it is made from.** The 40 mm 316 shaft that runs from behind the tower to just over the pit edge. It carries the large chain 1 sprocket, the chain 2 sprocket, the arm frame and the pivot tube's plug.

**How to make it.**

1. Saw 660 long; chamfer both ends with a file.
2. Mark from the rear end: rear bush at 40, large chain 1 sprocket at 185, front bush at 330, chain 2 sprocket at 480, arm frame bush 495 to 590, pivot tube plug 600 to 660.
3. Drill each sprocket's 6 mm roll pin hole through the hub and the shaft together, with the sprocket in place.
4. Polish the bush and plug lengths with fine emery.

**How it fits the parts next to it.**

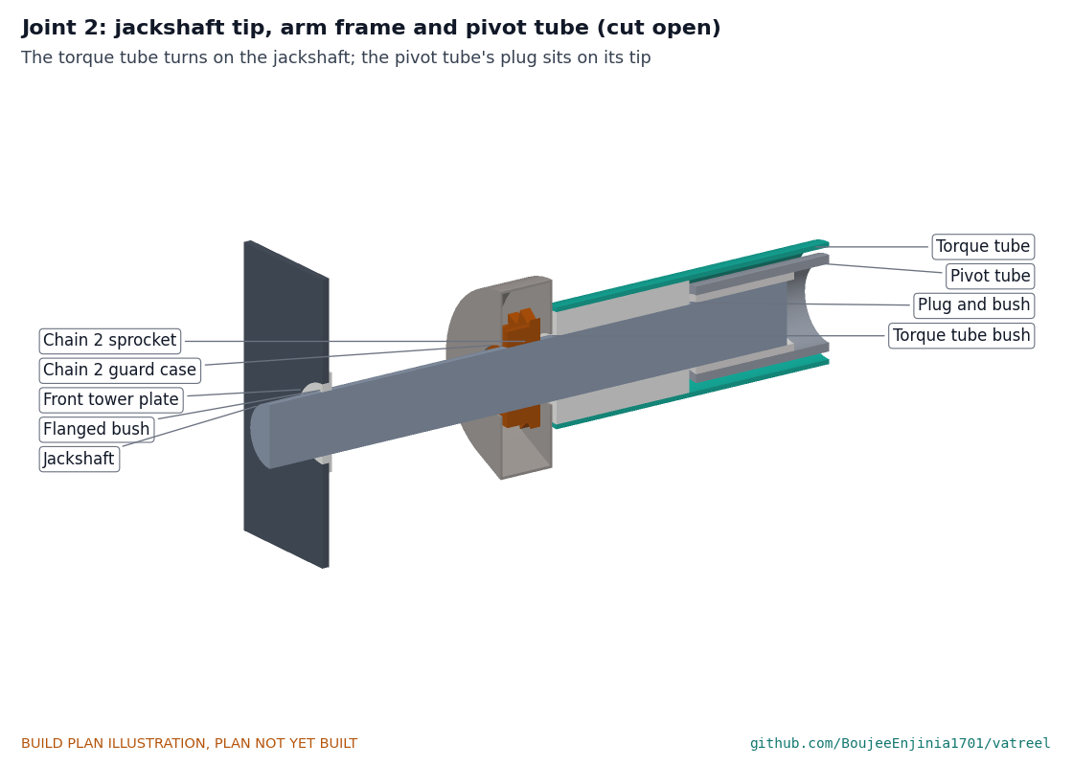
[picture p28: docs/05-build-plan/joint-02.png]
Figure 6. Joint 2: jackshaft tip, arm frame and pivot tube, cut open


*Figure 6. Joint 2. The torque tube's bush turns on the jackshaft just past the chain 2 case; the pivot tube's plug sits on the tip.*

**Check before moving on.** The shaft turns freely by hand in both tower bushes.

### 3.4 Crank shaft and crank

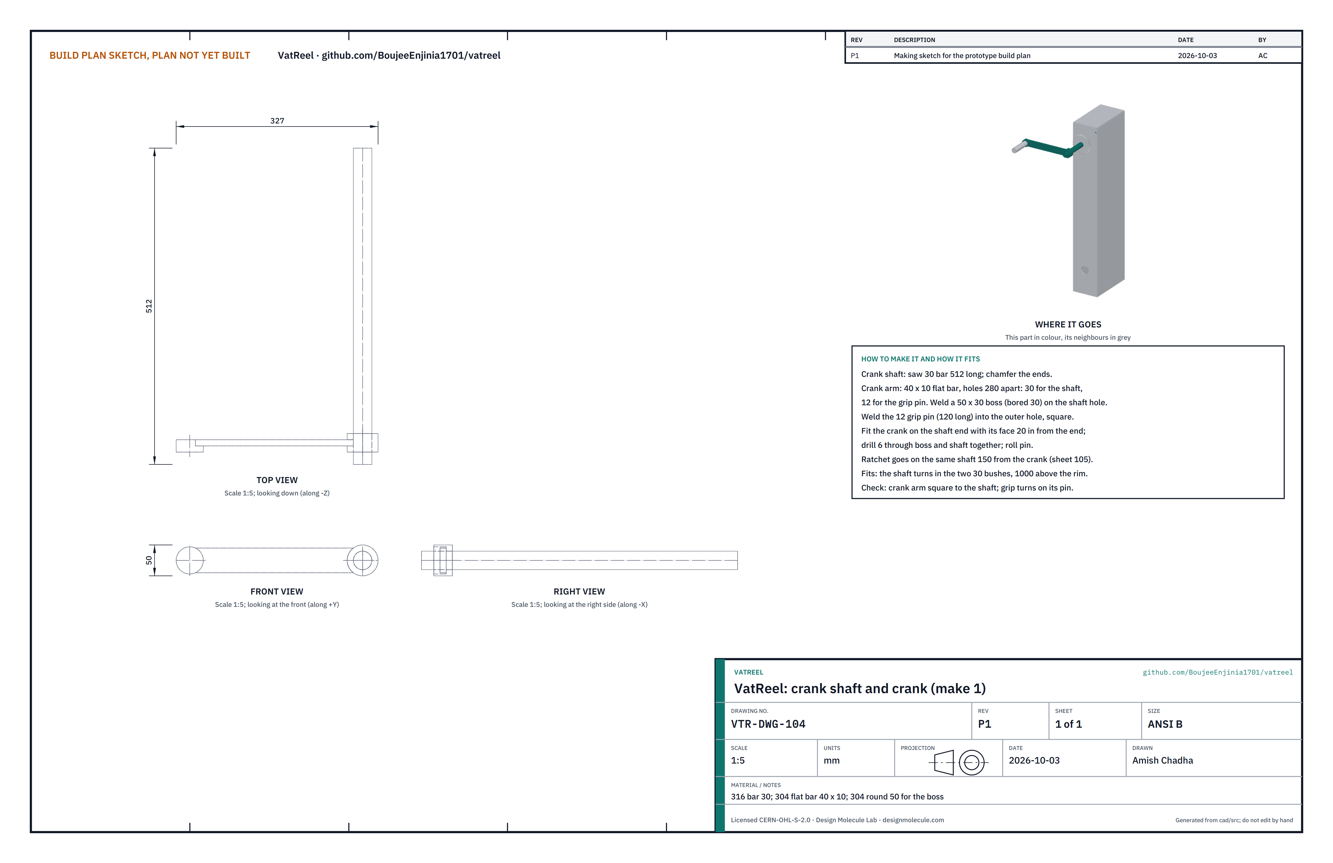
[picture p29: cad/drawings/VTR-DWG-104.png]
Figure 7. Making sketch of the crank shaft and crank


*Figure 7. Crank shaft and crank making sketch (VTR-DWG-104).*

**What it is and what it is made from.** A 30 mm 316 shaft 512 long, a crank arm of 40 x 10 flat bar with 280 between hole centres, and a bought turning grip on a 12 pin.

**How to make it.**

1. Saw and chamfer the shaft.
2. Drill the crank arm 30 and 12 at 280 centres; weld a 50 x 30 boss bored 30 over the shaft hole; weld the 12 pin, 120 long, in the outer hole, square to the arm.
3. Slide the crank onto the shaft, its face 20 in from the end; drill 6 through boss and shaft; roll pin.

**How it fits the parts next to it.** The shaft turns in the two 30 bushes; the small chain 1 sprocket sits between the tower plates and the ratchet just behind the rear plate.

**Check before moving on.** The crank arm is square to the shaft; the grip turns on its pin.

### 3.5 Ratchet, pawl and cover

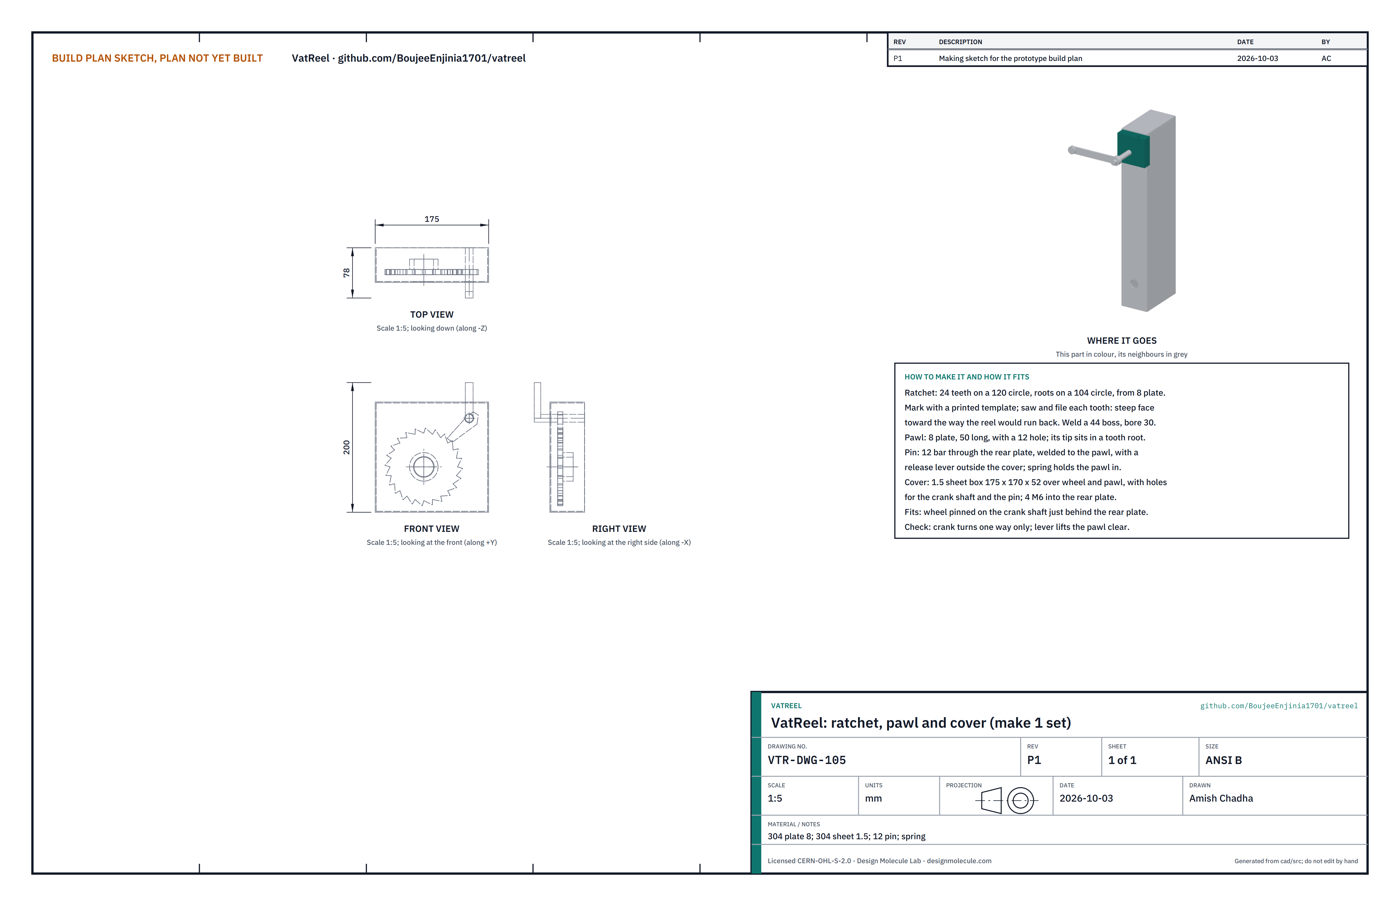
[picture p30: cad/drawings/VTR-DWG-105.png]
Figure 8. Making sketch of the ratchet, pawl and cover


*Figure 8. Ratchet, pawl and cover making sketch (VTR-DWG-105).*

**What it is and what it is made from.** The brake that holds the reel. A 24-tooth wheel 120 over the tips from 8 mm 304 plate, a pawl of the same plate on a 12 pin, a spring, and a 1.5 mm sheet cover.

**How to make it.**

1. Print a tooth template (roots on a 104 circle, tips on 120), glue it on the plate, saw and file each tooth with its steep face toward the way the reel would run back. Weld a 44 boss and bore it 30.
2. Make the pawl 50 long with a 12 hole; weld it to a 12 pin long enough to pass through the rear plate and the cover; weld a release lever on the pin's outer end.
3. Bend the cover as a box 175 x 170 x 52 with holes for the crank shaft and the pawl pin; drill four M6 holes into the rear plate.

**How it fits the parts next to it.**

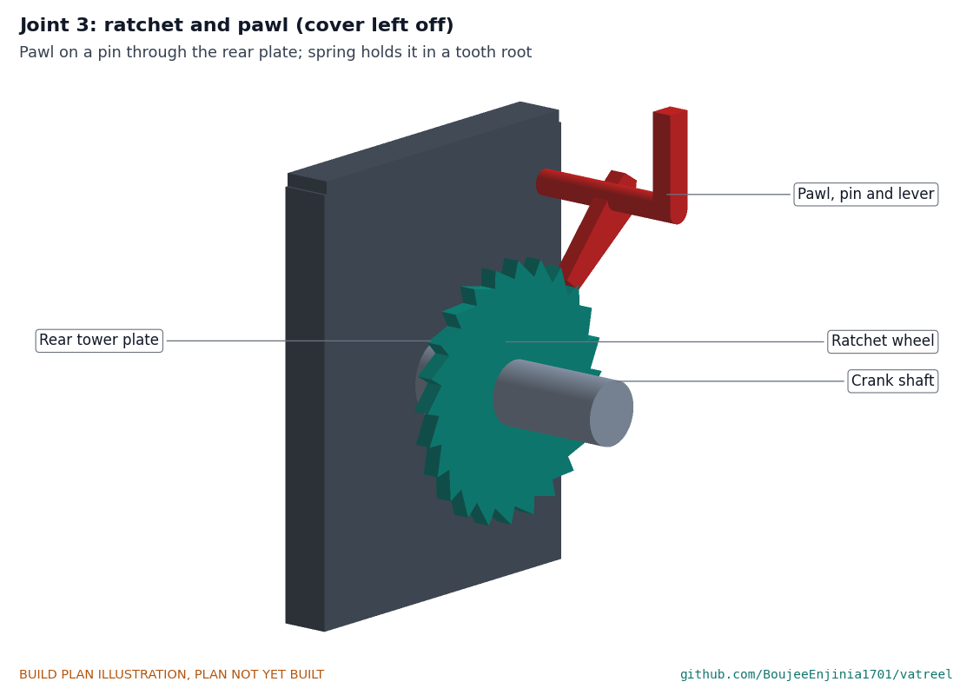
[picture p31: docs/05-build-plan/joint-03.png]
Figure 9. Joint 3: ratchet and pawl, cover left off


*Figure 9. Joint 3. The pawl pivots on its pin through the rear plate; the spring holds its tip in a tooth root.*

**Check before moving on.** The crank turns one way only; lifting the release lever lets it turn back.

### 3.6 Splash shield

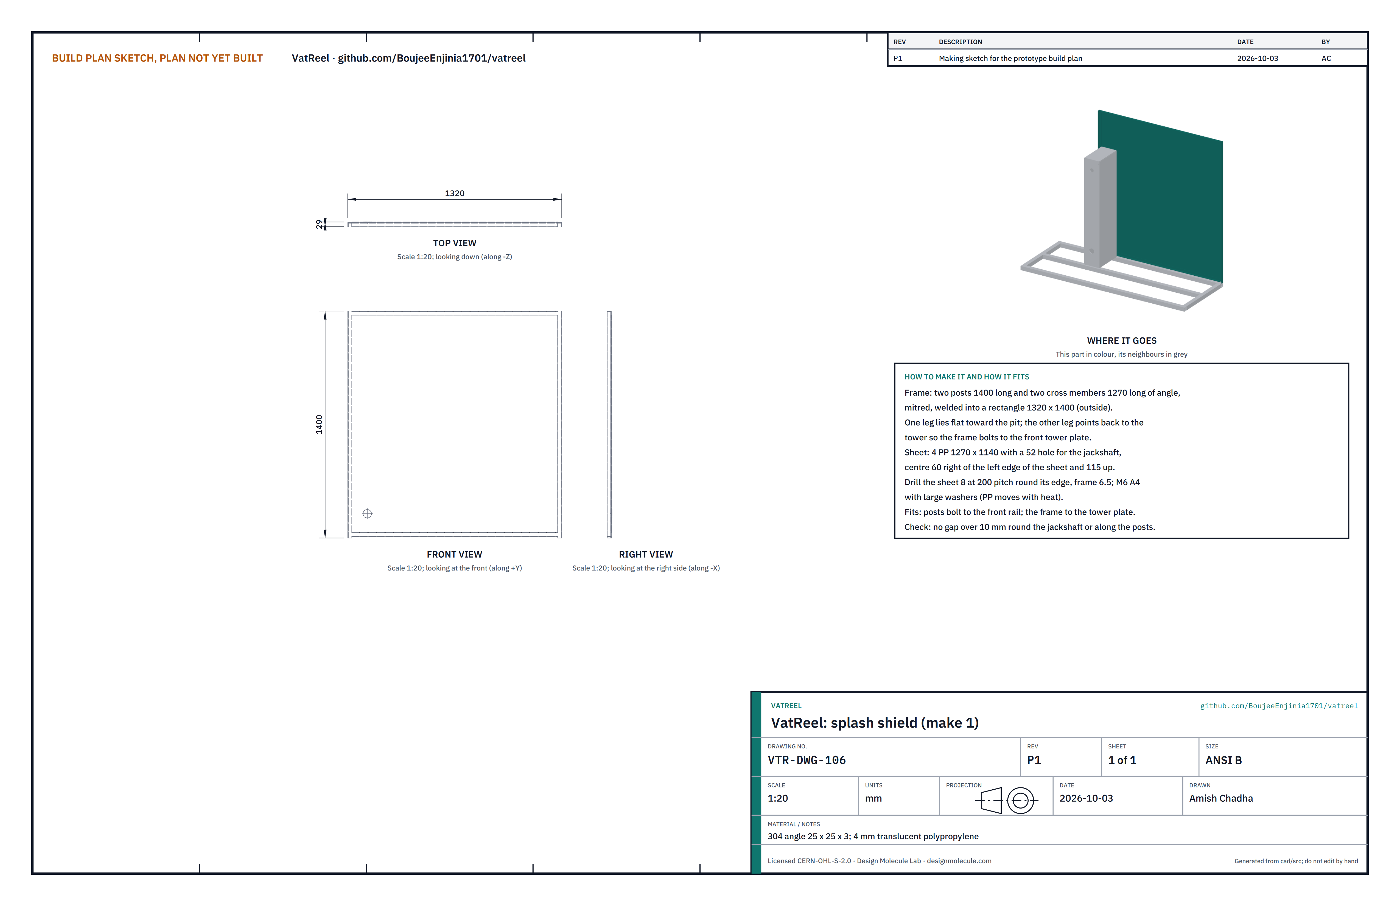
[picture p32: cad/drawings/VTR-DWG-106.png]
Figure 10. Making sketch of the splash shield


*Figure 10. Splash shield making sketch (VTR-DWG-106).*

**What it is and what it is made from.** A clear barrier between the reel and the operator. A rectangle of 25 x 25 x 3 304 angle, 1,320 wide and 1,400 high outside, and a 4 mm translucent polypropylene sheet 1,270 x 1,140.

**How to make it.**

1. Saw two posts 1,400 and two cross members 1,270; mitre and weld into a rectangle, one leg of each angle flat toward the pit and the other leg pointing back to the tower.
2. Cut the sheet; cut a 52 hole for the jackshaft, centred 60 in from the sheet's left edge and 115 up from its bottom edge (check against the tower before cutting).
3. Drill the sheet 8 at 200 pitch round its edge and the frame 6.5; fix with M6 A4 bolts and large washers so the sheet can move with heat.

**How it fits the parts next to it.**

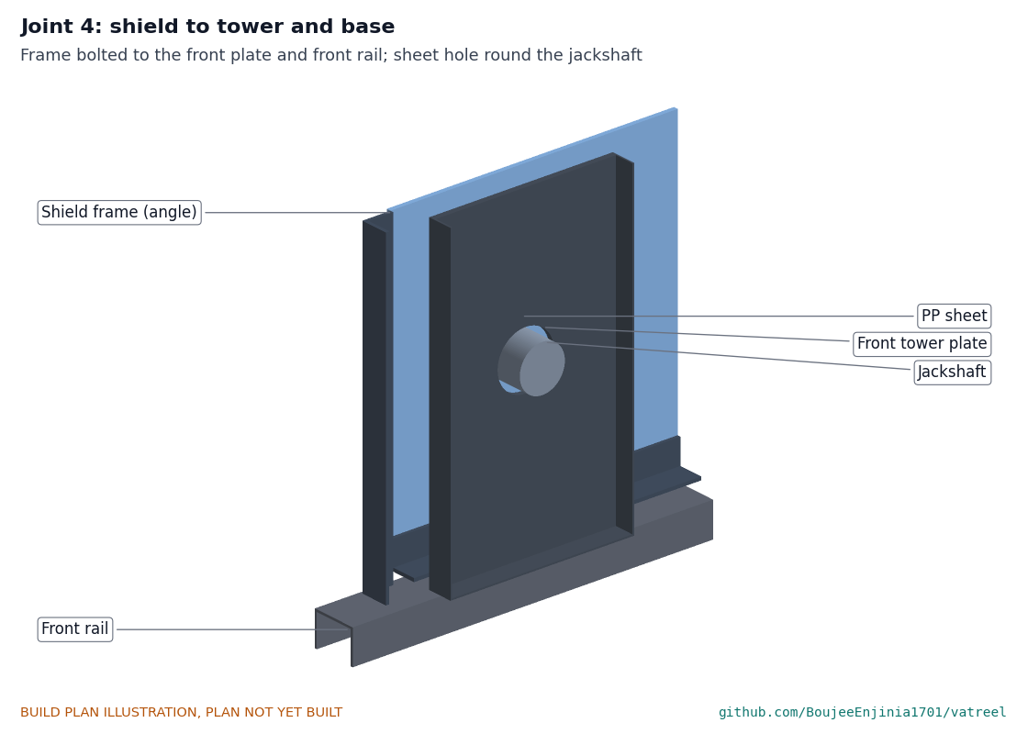
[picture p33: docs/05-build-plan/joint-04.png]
Figure 11. Joint 4: shield to tower and base


*Figure 11. Joint 4. The frame bolts to the front tower plate and to the front rail; the sheet's hole clears the jackshaft.*

**Check before moving on.** No gap wider than 10 mm round the jackshaft or along the posts.

### 3.7 Lift screw bracket

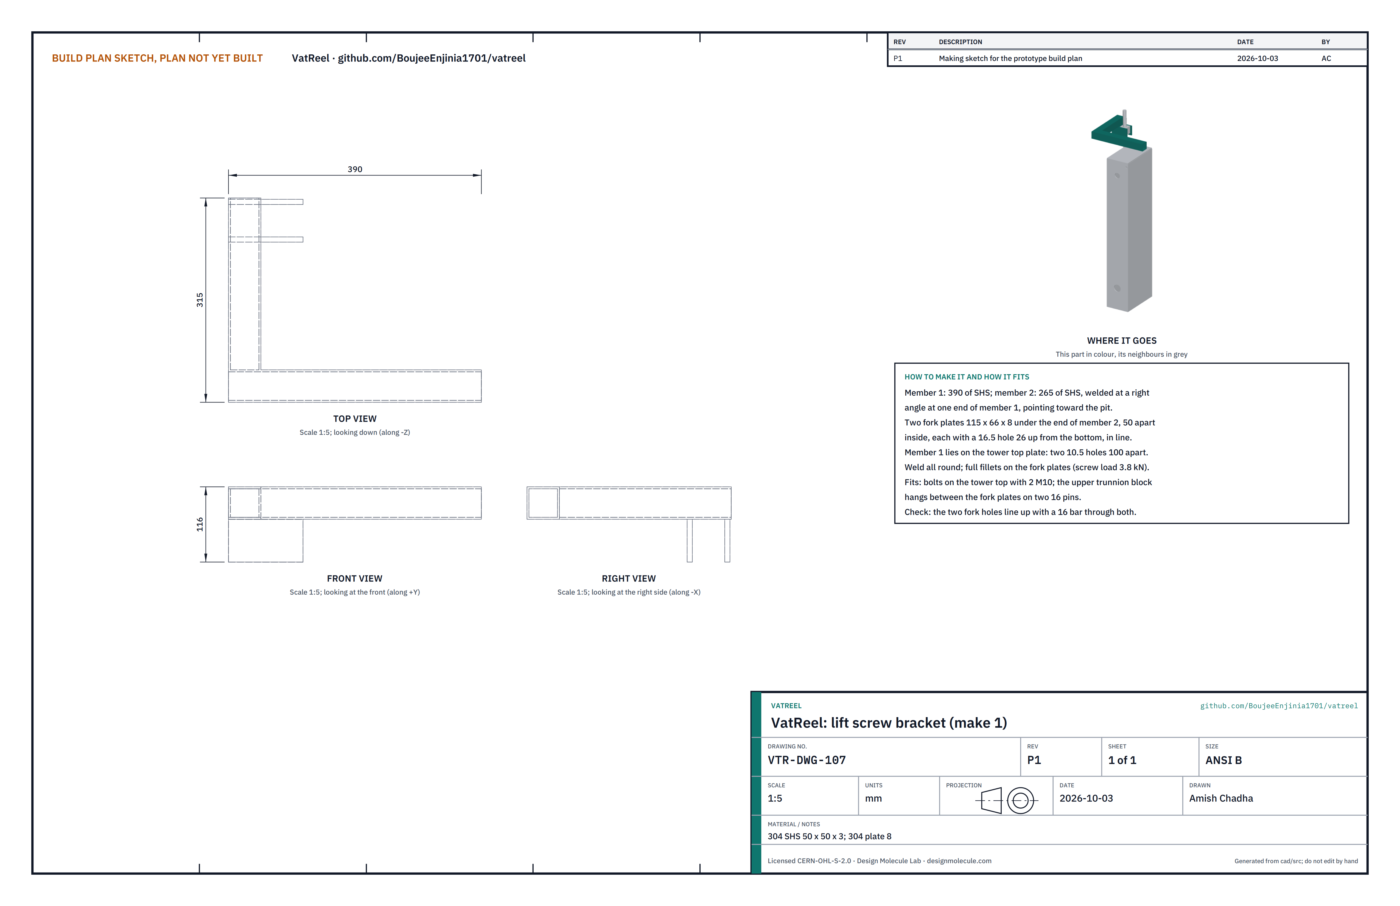
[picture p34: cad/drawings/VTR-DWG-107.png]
Figure 12. Making sketch of the lift screw bracket


*Figure 12. Lift screw bracket making sketch (VTR-DWG-107).*

**What it is and what it is made from.** An L of 50 x 50 x 3 304 tube that reaches from the tower top out over the pit's end, with two 8 mm fork plates that hold the upper trunnion.

**How to make it.**

1. Saw a 390 and a 265 length; weld them at a right angle.
2. Weld the two fork plates (115 x 66 x 8) under the end of the short member, 50 apart inside; drill both 16.5 together, 26 up from their lower edge.
3. Drill two 10.5 holes 100 apart in the long member for the tower top.
4. Weld all round with full fillets; the screw pushes up on this bracket with up to 3.8 kN.

**How it fits the parts next to it.** The long member bolts on the tower top with two M10; the upper trunnion hangs between the forks on two pins (Figure 28).

**Check before moving on.** A 16 bar passes through both fork holes.

### 3.8 Trunnion blocks

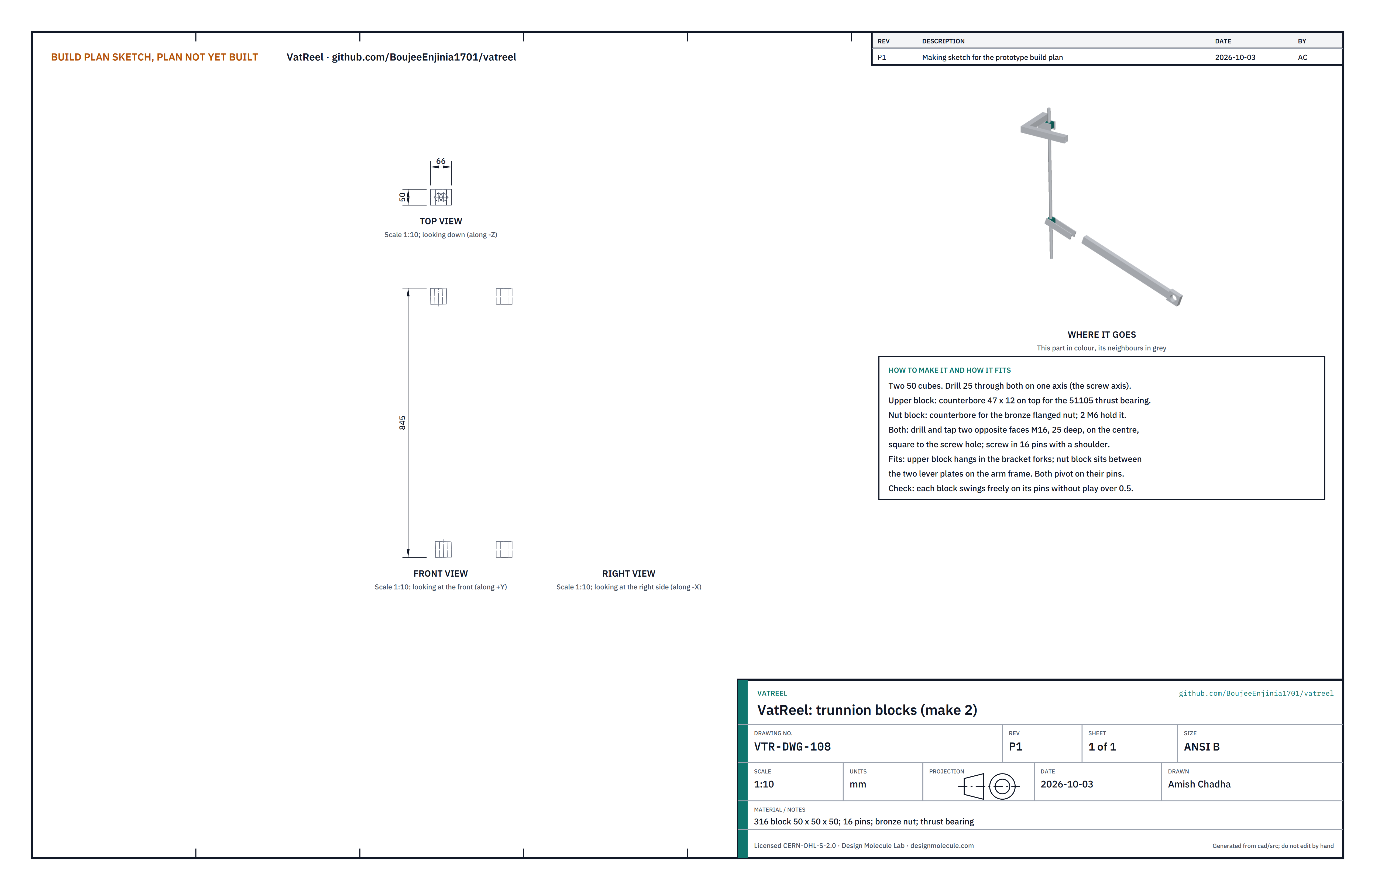
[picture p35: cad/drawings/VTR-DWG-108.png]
Figure 13. Making sketch of the trunnion blocks


*Figure 13. Trunnion blocks making sketch (VTR-DWG-108).*

**What it is and what it is made from.** Two 50 mm 316 cubes. The upper block carries the screw in a thrust ball bearing; the lower block holds the bronze nut between the lever plates on the arm frame.

**How to make it.**

1. Drill 25 through each cube for the screw.
2. Upper block: counterbore 47 x 12 on top for the 51105 thrust bearing. Nut block: counterbore for the nut's flange; two M6 hold the nut.
3. On two opposite faces of each block, square to the screw hole, drill and tap M16 25 deep; screw in 16 pins with a shoulder.

**How it fits the parts next to it.** Each block pivots on its two pins; the screw turns in the upper bearing and the bronze nut.

**Check before moving on.** Each block swings on its pins with no more than 0.5 of play.

### 3.9 Pivot tube with plug

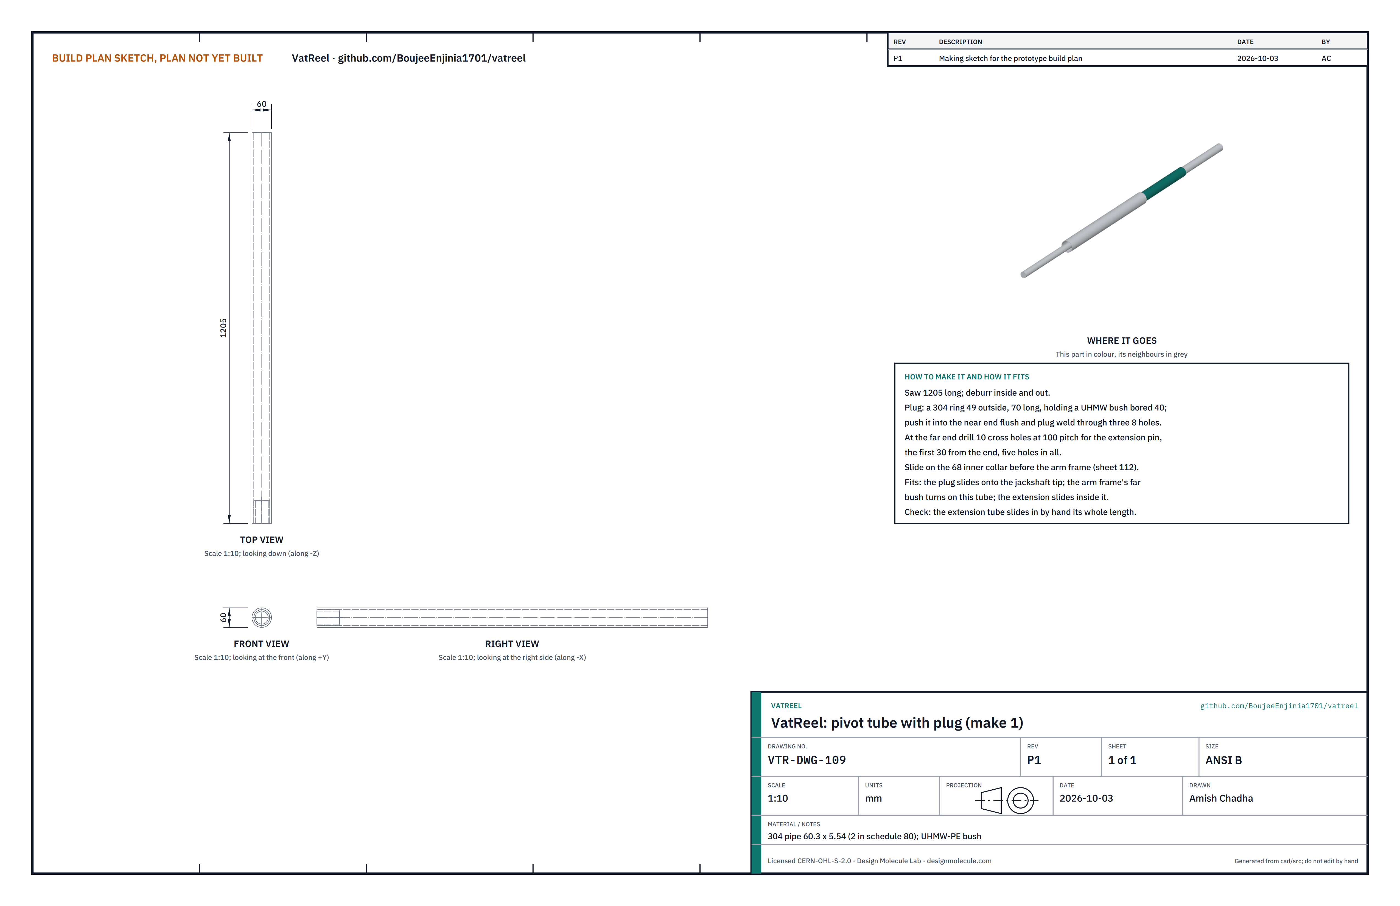
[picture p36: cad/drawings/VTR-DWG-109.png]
Figure 14. Making sketch of the pivot tube


*Figure 14. Pivot tube making sketch (VTR-DWG-109).*

**What it is and what it is made from.** The tube the arm frame swings on. 304 pipe 60.3 x 5.54 (2 inch schedule 80), 1,205 long, with a plug and UHMW-PE bush bored 40 in its near end.

**How to make it.**

1. Saw and deburr inside and out.
2. Push the plug ring with its bush into the near end, flush; plug weld through three 8 holes.
3. Drill five 10 cross holes at 100 pitch for the extension pin, the first 30 from the far end.
4. Slide the inner shaft collar (68) onto the tube before the arm frame goes on.

**How it fits the parts next to it.**

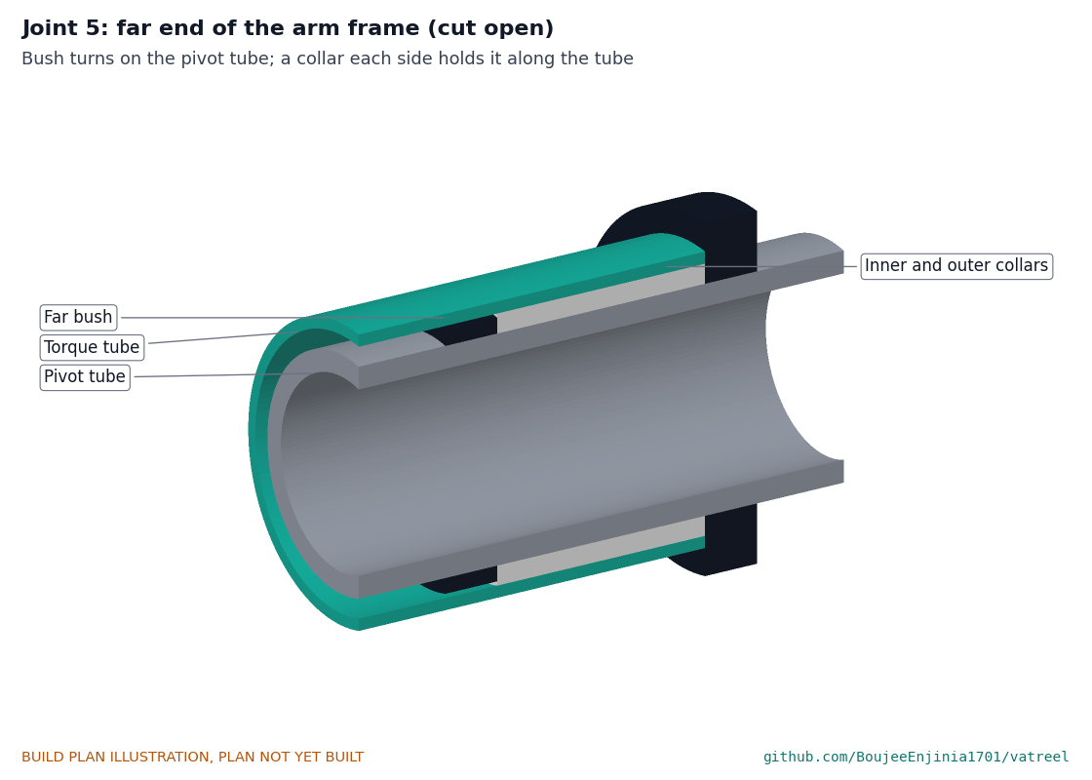
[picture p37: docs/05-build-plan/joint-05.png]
Figure 15. Joint 5: far end of the arm frame, cut open


*Figure 15. Joint 5. The far bush turns on the pivot tube; a collar on each side holds it along the tube.*

**Check before moving on.** The extension tube slides inside by hand its whole length.

### 3.10 Extension tube

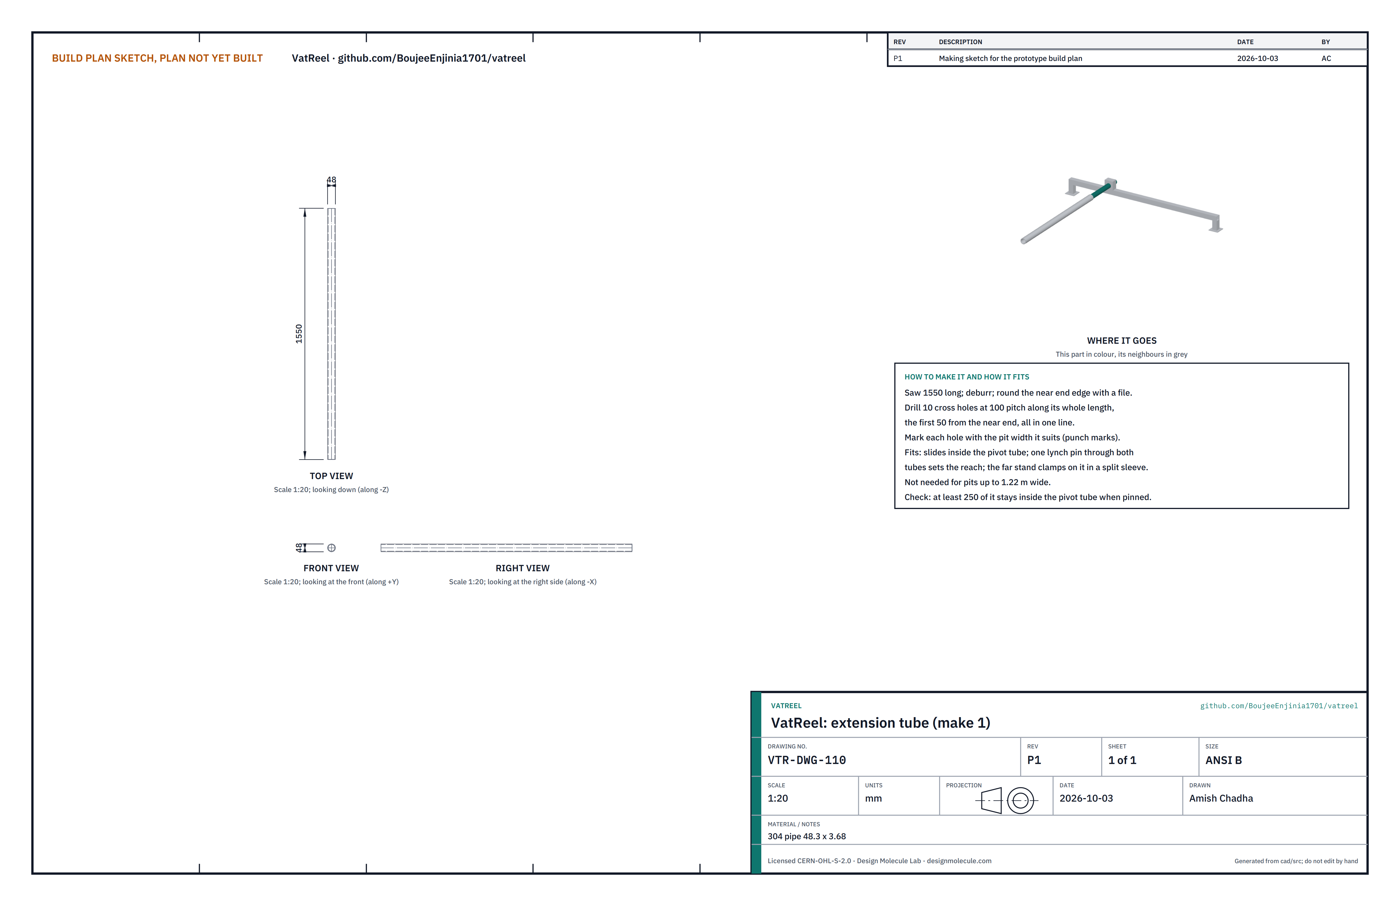
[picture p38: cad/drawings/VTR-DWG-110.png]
Figure 16. Making sketch of the extension tube


*Figure 16. Extension tube making sketch (VTR-DWG-110).*

**What it is and what it is made from.** 304 pipe 48.3 x 3.68, 1,550 long, with a 10 lynch pin on a lanyard. Needed only for pits wider than 1.22 m.

**How to make it.**

1. Saw, deburr and round the near end edge with a file.
2. Drill 10 cross holes at 100 pitch along its length, the first 50 from the near end, in one line.
3. Punch-mark each hole with the pit width it suits.

**How it fits the parts next to it.**

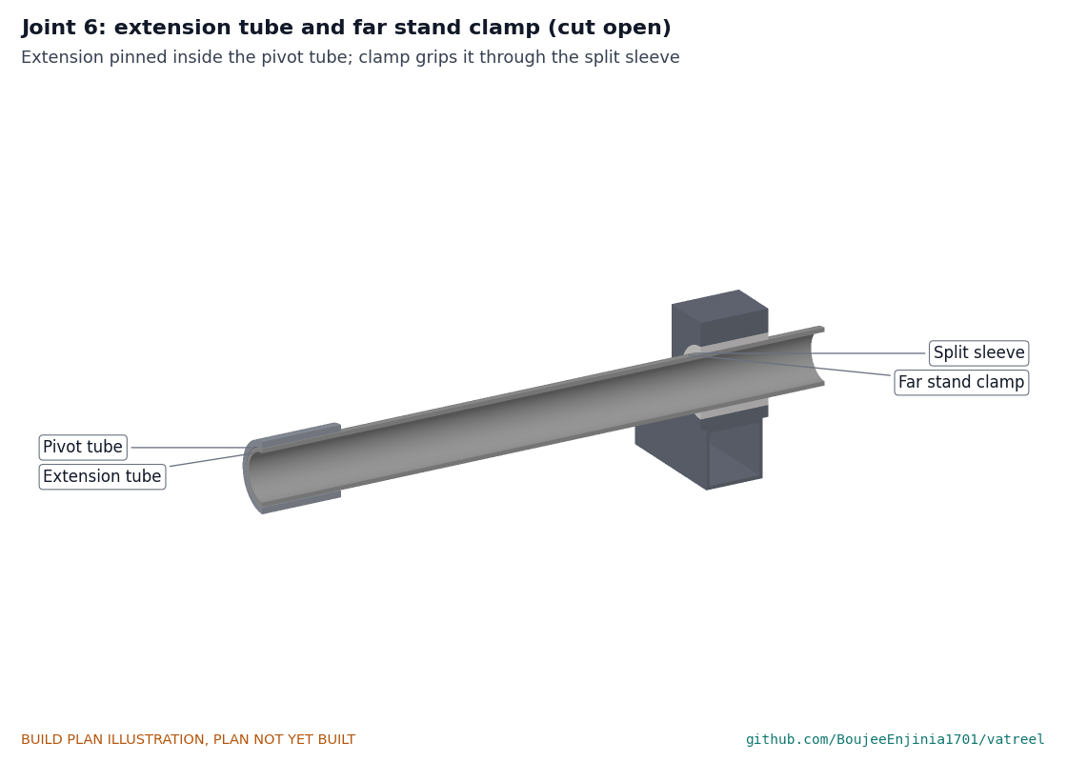
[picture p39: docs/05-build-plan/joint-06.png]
Figure 17. Joint 6: extension tube and far stand clamp, cut open


*Figure 17. Joint 6. The extension is pinned inside the pivot tube; the far stand's clamp grips it through the split sleeve.*

**Check before moving on.** When pinned, at least 250 of it stays inside the pivot tube.

### 3.11 Far stand

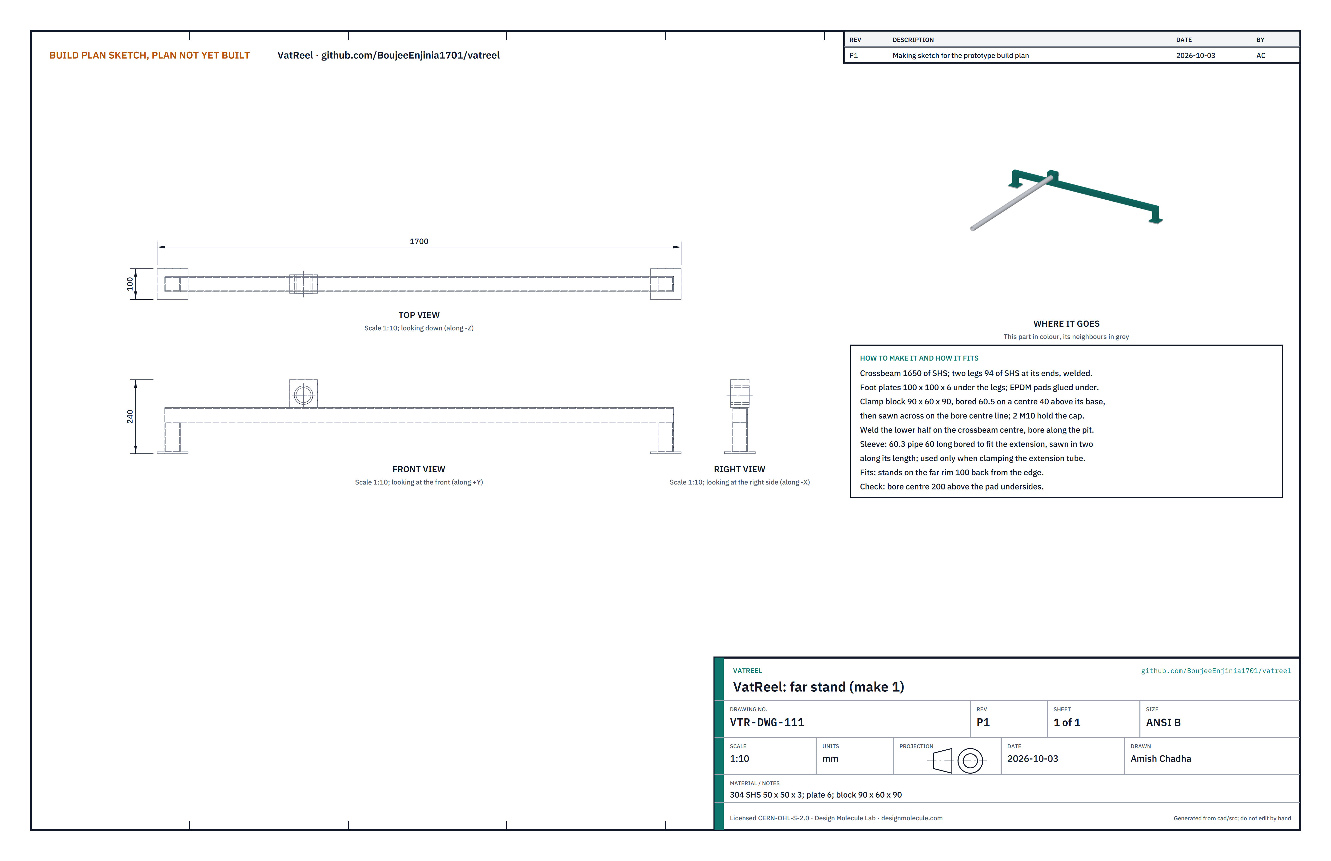
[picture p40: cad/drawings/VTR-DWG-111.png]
Figure 18. Making sketch of the far stand


*Figure 18. Far stand making sketch (VTR-DWG-111).*

**What it is and what it is made from.** A beam on two short legs that stands on the far rim and clamps the end of the tube. 304 tube 50 x 50 x 3, 6 mm foot plates, a 90 x 60 x 90 clamp block, a split sleeve and two EPDM pads.

**How to make it.**

1. Saw the crossbeam 1,650 and two legs 94; weld the legs under the ends and the foot plates under the legs.
2. Bore the clamp block 60.5 with the bore centre 40 above its base; saw it across on the bore centre line; drill and tap for two M10 to hold the cap.
3. Weld the lower half on the middle of the beam, bore along the pit's width.
4. Saw a 60 length of 60.3 pipe, bore it to fit the extension and saw it in two along its length (the sleeve).

**How it fits the parts next to it.** The clamp closes on the pivot tube directly, or on the extension through the sleeve (Figure 17).

**Check before moving on.** The bore centre is 200 above the underside of the pads.

### 3.12 Arm frame

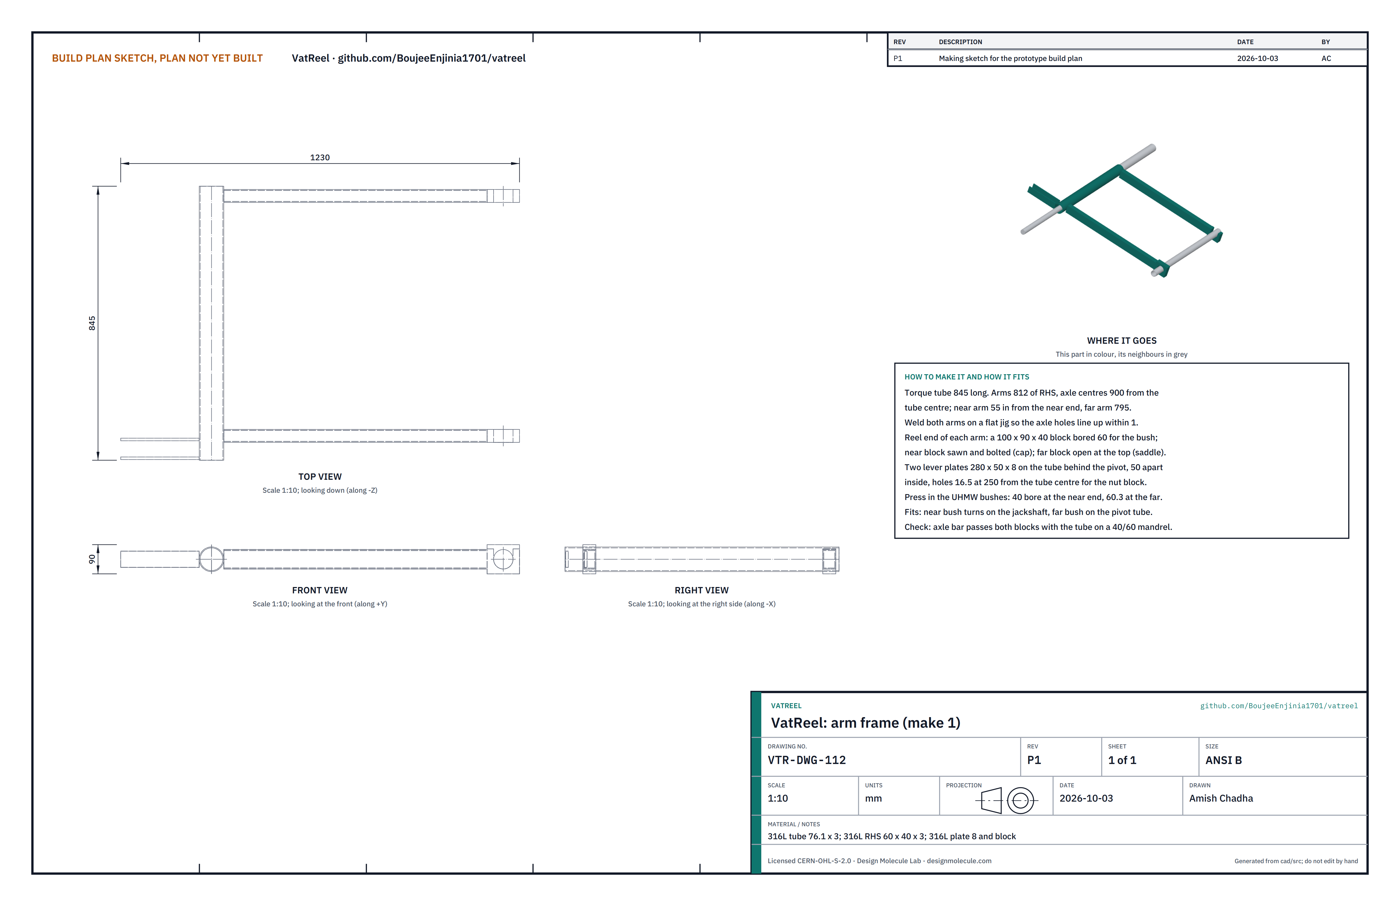
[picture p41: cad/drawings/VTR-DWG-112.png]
Figure 19. Making sketch of the arm frame


*Figure 19. Arm frame making sketch (VTR-DWG-112), drawn with the arms level.*

**What it is and what it is made from.** The welded U that carries the reel: a 316L torque tube 76.1 x 3, 845 long, two arms of 316L rectangular tube 60 x 40 x 3, a split bearing block on the near arm and an open saddle on the far arm, two lever plates, and a keeper.

**How to make it.**

1. Saw the torque tube and two arms 812 long.
2. Make a flat jig that holds the torque tube and puts the two bearing centres 900 from the tube centre, in line. Near arm 55 in from the tube's near end, far arm 795 in.
3. Weld a 100 x 90 x 40 block on the reel end of each arm and bore both 60 in line with the jig. Saw the near block across its centre and drill it for two M8 cap bolts. On the far block cut a 60 slot from the top down to the bore centre (the saddle).
4. Weld two lever plates (280 x 50 x 8) on the torque tube on the side away from the arms, 50 apart inside; drill 16.5 holes at 250 from the tube centre for the nut block.
5. Make the keeper (80 x 40 x 8 plate) hinged on one side of the saddle, closing over the slot, with a pin hole on the other side.
6. Press the UHMW-PE bushes into the torque tube: bore 40 at the near end, 60.3 at the far end. Pickle all welds.

**How it fits the parts next to it.** The near bush turns on the jackshaft and the far bush on the pivot tube (Figures 6 and 15); the nut block sits between the lever plates (Figure 27).

**Check before moving on.** A straight bar passes through both bearing blocks with the frame on a 40 and 60 mm stepped mandrel.

### 3.13 Chain 2 guard

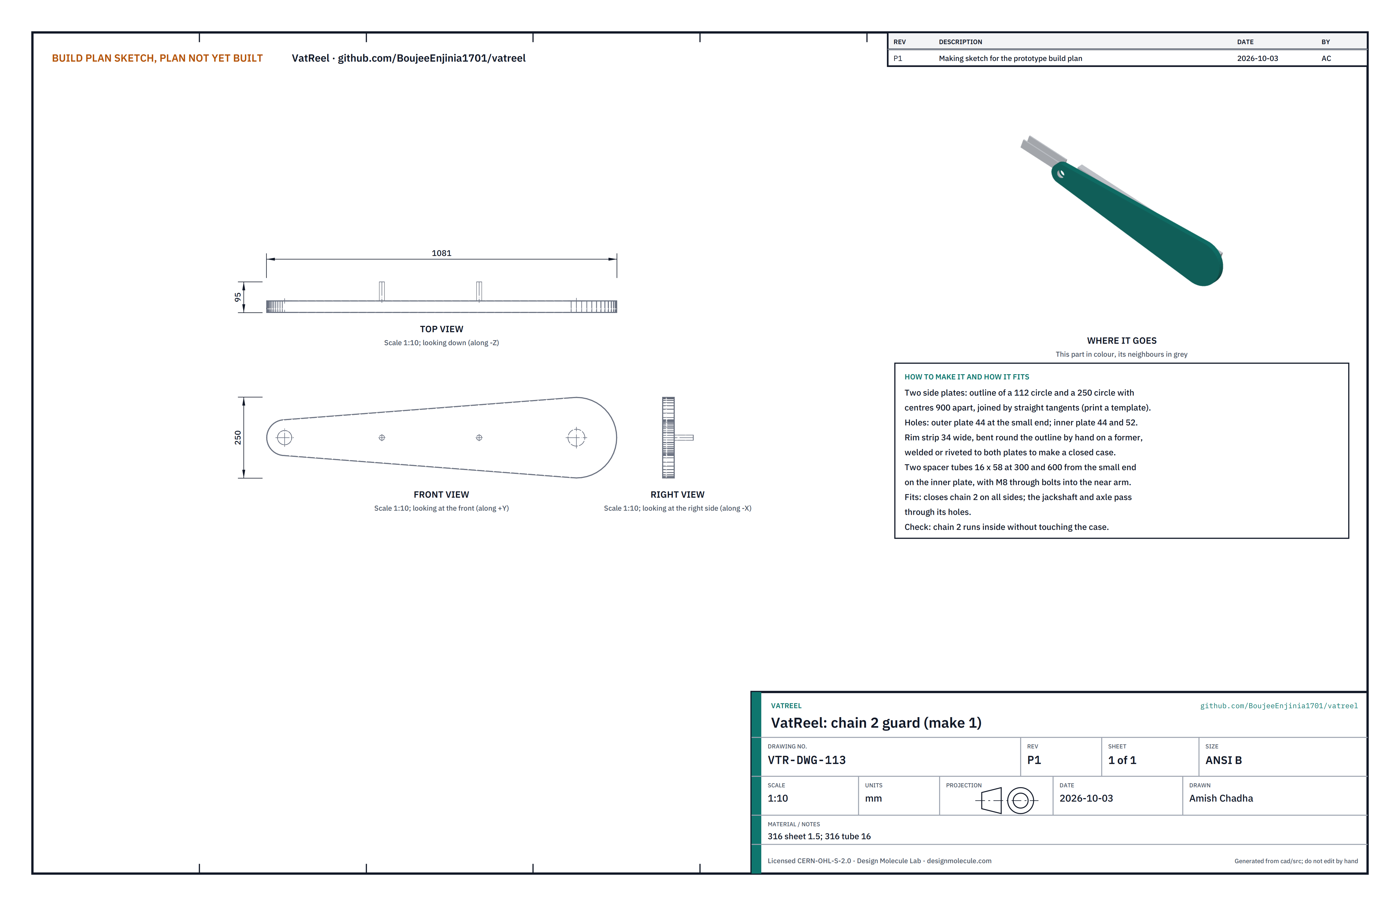
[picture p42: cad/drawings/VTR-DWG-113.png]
Figure 20. Making sketch of the chain 2 guard


*Figure 20. Chain 2 guard making sketch (VTR-DWG-113).*

**What it is and what it is made from.** A closed case of 1.5 mm 316 sheet round chain 2.

**How to make it.**

1. Print a template: a 112 circle and a 250 circle with centres 900 apart, joined by straight tangent lines. Cut two side plates.
2. Holes: 44 at the small end of both plates; 52 at the large end of the inner plate only.
3. Bend a 34 wide strip round the outline on a plywood former; weld or rivet it to both plates.
4. Weld two spacer tubes 16 x 58 on the inner plate at 300 and 600 from the small end; drill for M8 through bolts.

**How it fits the parts next to it.** It bolts to the near arm on the spacers; the jackshaft and the axle pass through its holes (Figure 22).

**Check before moving on.** Chain 2, joined loosely inside, does not touch the case.

### 3.14 Reel

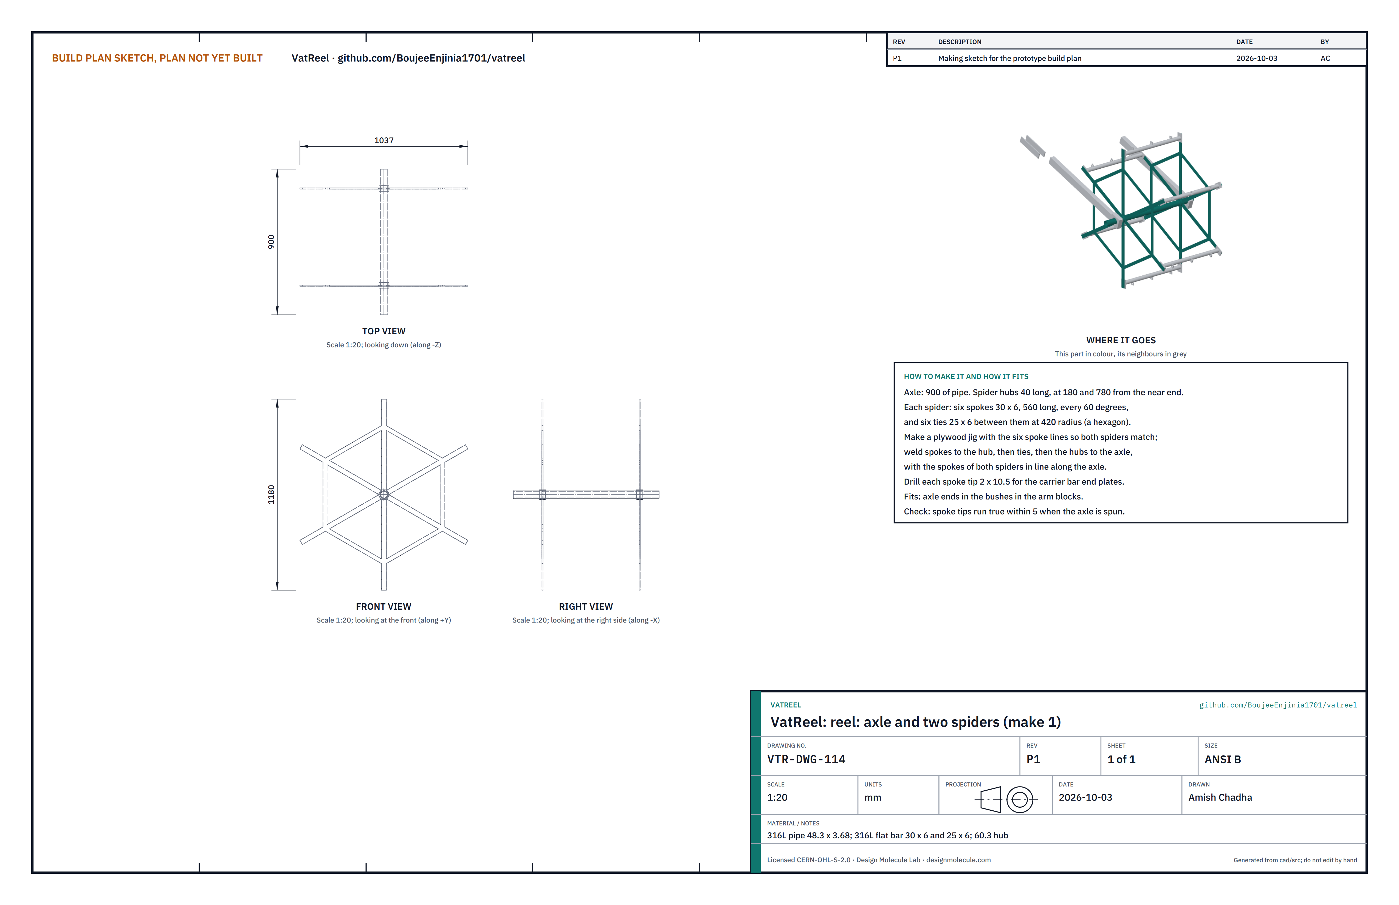
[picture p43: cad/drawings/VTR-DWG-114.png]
Figure 21. Making sketch of the reel


*Figure 21. Reel making sketch (VTR-DWG-114), drawn with the axle level.*

**What it is and what it is made from.** A 316L axle 48.3 x 3.68, 900 long, with two spiders, each six 30 x 6 spokes 560 long on a 40 long hub sleeve, braced by six 25 x 6 ties at 420 radius.

**How to make it.**

1. Make a plywood jig with six spoke lines at 60 degrees and a centre peg for the hub sleeve.
2. For each spider, weld the six spokes to a hub sleeve in the jig, then the six ties between the spokes.
3. Slide both spiders on the axle, 180 and 780 from its near end, with the spokes of both in line along the axle (check with a straight edge); weld the hubs to the axle.
4. Drill each spoke tip 2 x 10.5 for the carrier bar end plates. Pickle all welds.

**How it fits the parts next to it.**

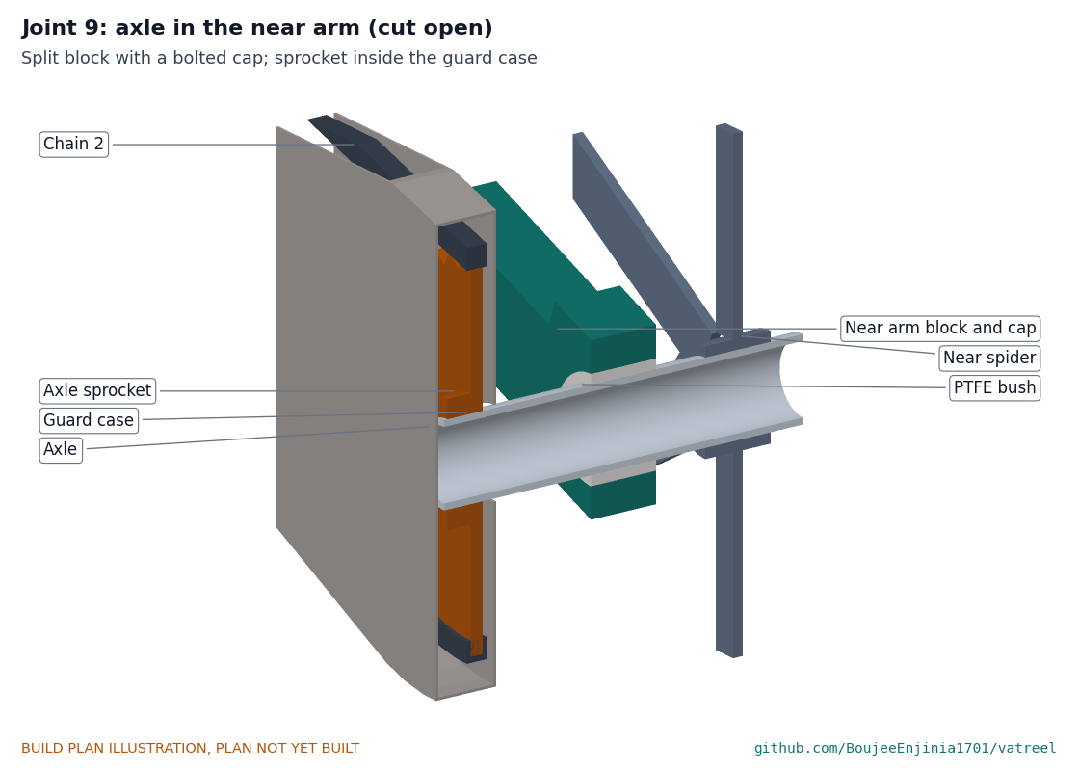
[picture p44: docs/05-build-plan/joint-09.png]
Figure 22. Joint 9: axle in the near arm, cut open


*Figure 22. Joint 9. The axle turns in a glass-filled PTFE bush in the split block; the axle sprocket sits inside the guard case on the wall side.*

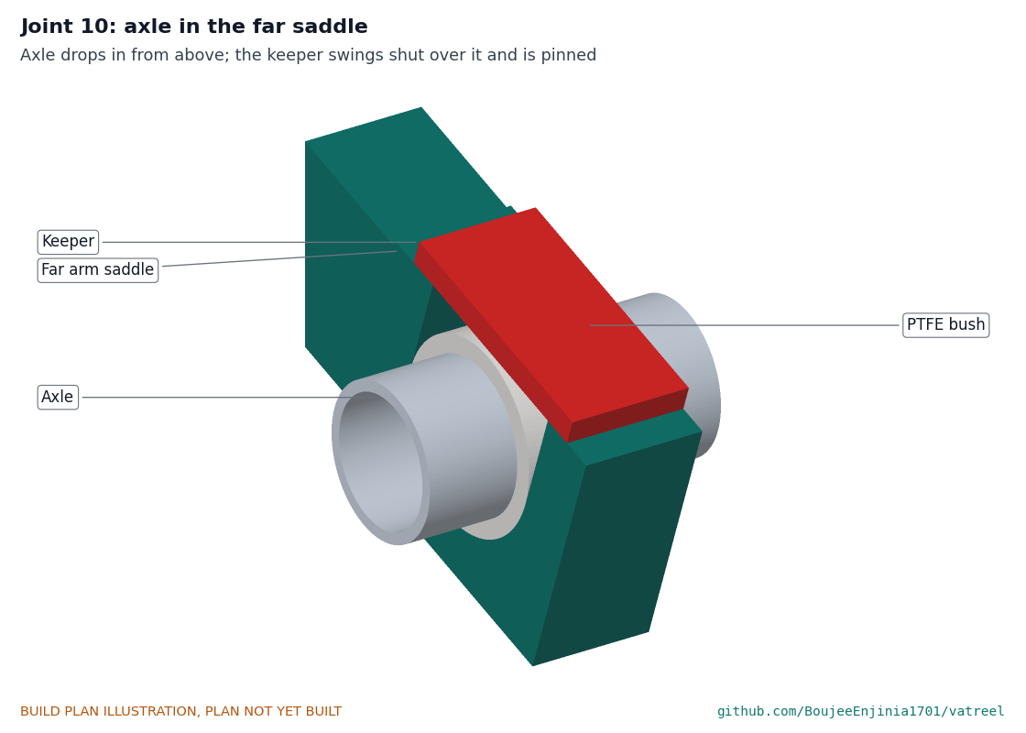
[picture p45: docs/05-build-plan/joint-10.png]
Figure 23. Joint 10: axle in the far saddle


*Figure 23. Joint 10. The axle drops into the open saddle from above; the keeper swings shut over it and is pinned.*

**Check before moving on.** Spun on its axle, the spoke tips run true within 5.

### 3.15 Carrier bars (make 6)

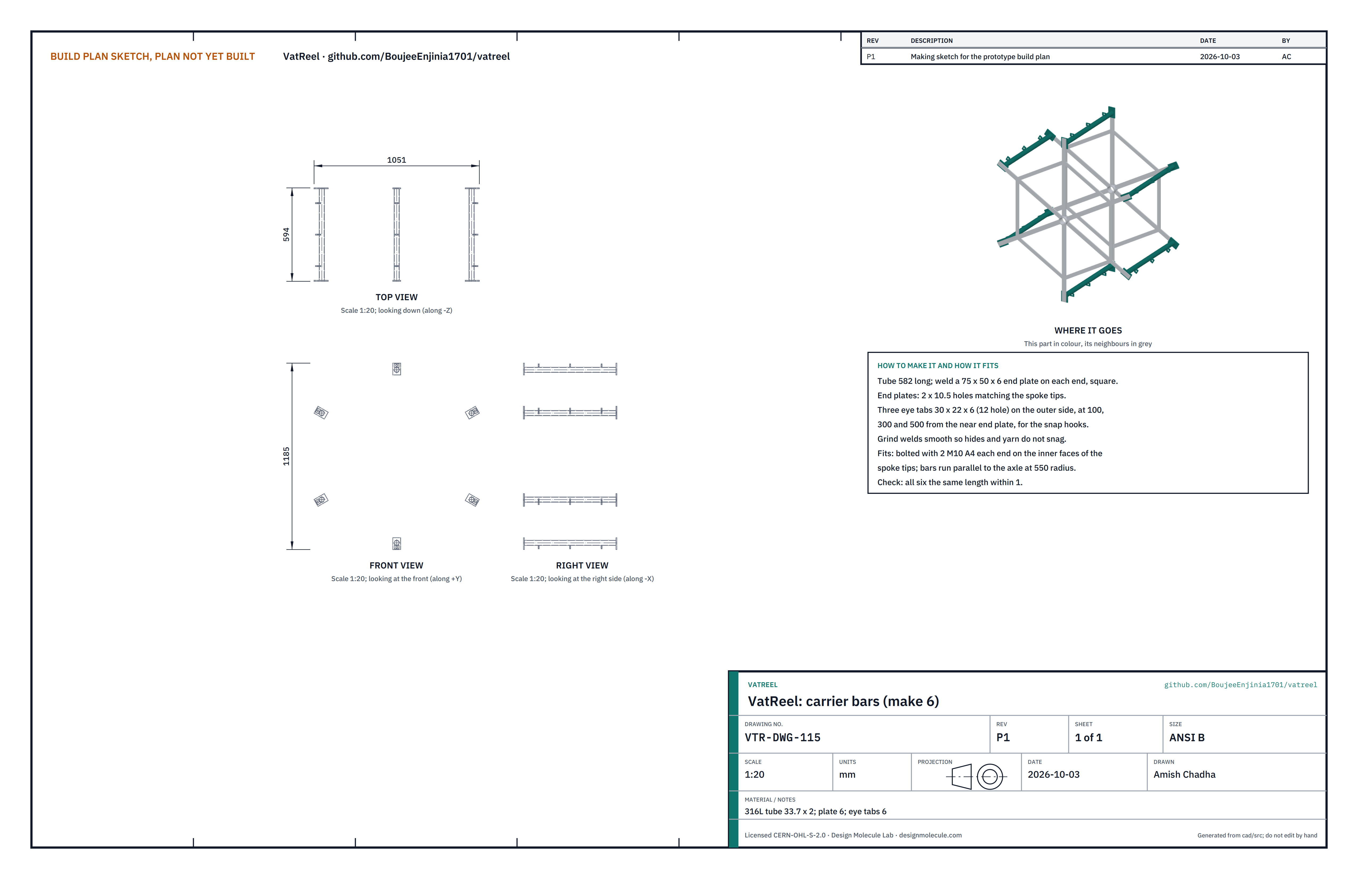
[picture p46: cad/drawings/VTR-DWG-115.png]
Figure 24. Making sketch of the carrier bars


*Figure 24. Carrier bar making sketch (VTR-DWG-115).*

**What it is and what it is made from.** 316L tube 33.7 x 2, 582 long, with a 75 x 50 x 6 end plate on each end and three eye tabs for snap hooks.

**How to make it.**

1. Saw six tubes to the same length within 1; weld the end plates square.
2. Drill each end plate 2 x 10.5 to match the spoke tips.
3. Weld three eye tabs (30 x 22 x 6, 12 hole) on the outer side at 100, 300 and 500 from the near end plate.
4. Grind every weld smooth so hides and yarn do not snag; pickle.

**How it fits the parts next to it.**

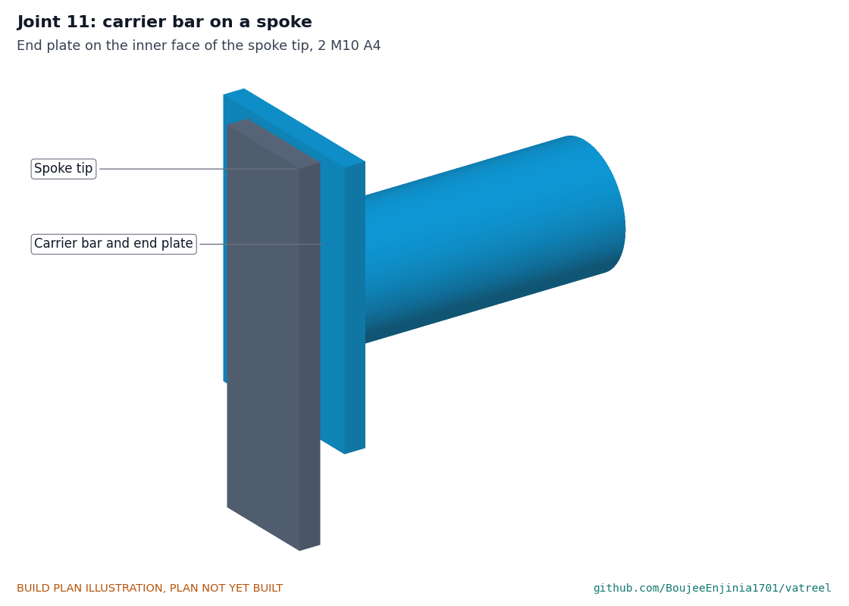
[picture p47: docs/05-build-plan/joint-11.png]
Figure 25. Joint 11: carrier bar on a spoke


*Figure 25. Joint 11. Each end plate bolts to the inner face of a spoke tip with two M10 A4.*

**Check before moving on.** All six bars are parallel to the axle and the reel still runs true.

### 3.16 Loading hooks (make 2)

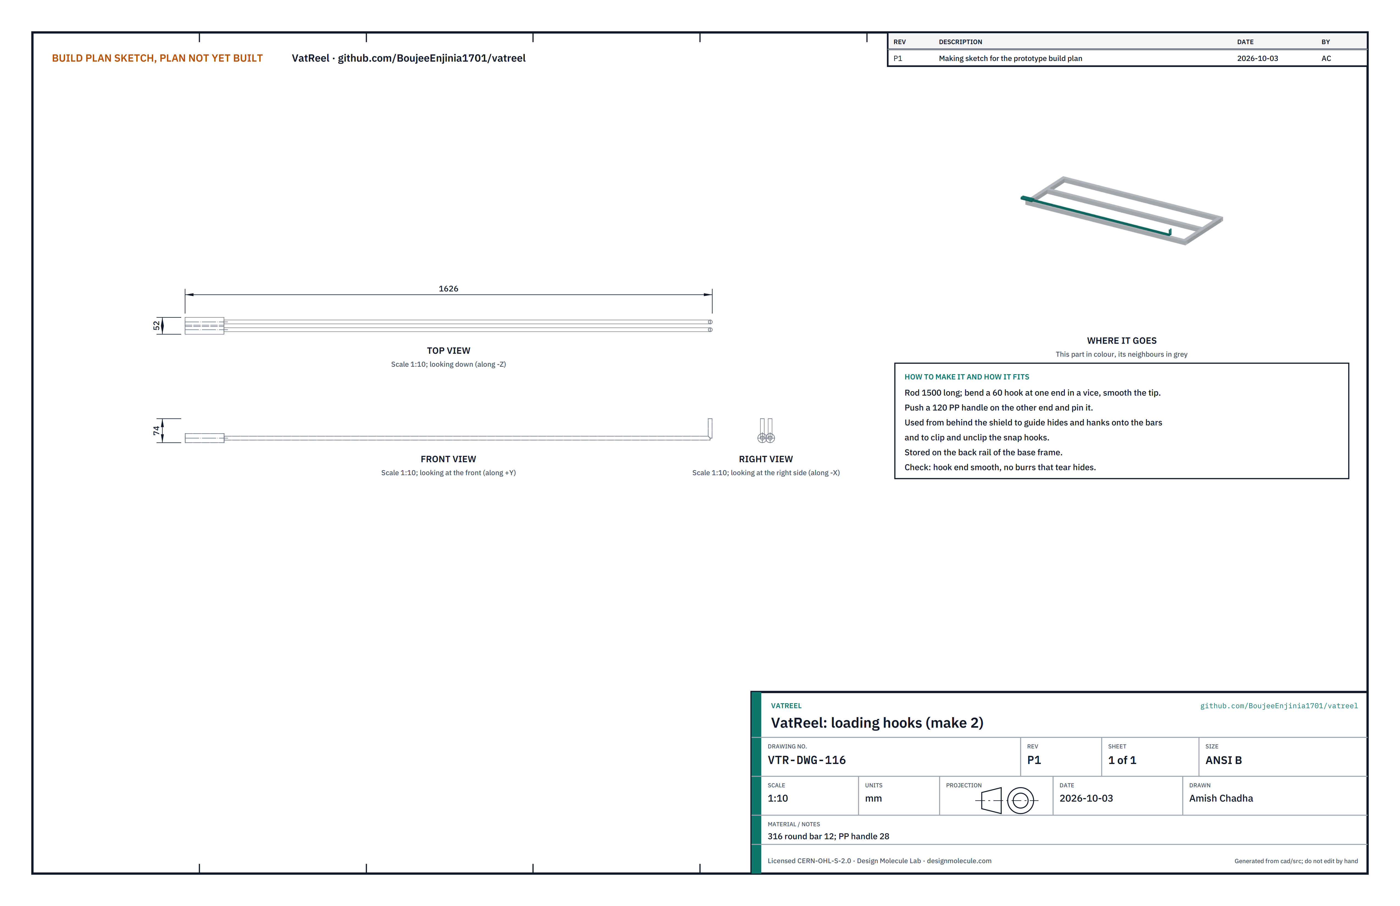
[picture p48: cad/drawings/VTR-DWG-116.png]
Figure 26. Making sketch of the loading hooks


*Figure 26. Loading hook making sketch (VTR-DWG-116).*

**What it is and what it is made from.** 12 mm 316 rod 1,500 long with a 60 mm hook and a polypropylene handle.

**How to make it.** Bend the hook in a vice and smooth the tip; push on and pin the handle.

**How it fits the parts next to it.** Used from behind the shield to guide hides and hanks and to clip snap hooks; kept on the base frame's back rail.

**Check before moving on.** No burrs on the hook.

### 3.17 Lift screw (bought)

**What to buy.** Tr24 x 5 single-start threaded rod in 316 stainless (2 m, cut to 1,250); a bronze Tr24 x 5 flanged nut; a 51105 stainless thrust ball bearing; a 250 mm handwheel with a spinner.

**What to do to it.** Saw the rod to 1,250. Buy the handwheel with a 24 bore so it fits the rod as it is; drill 6 through the handwheel hub and rod; roll pin. Run the nut along the whole thread by hand before fitting.

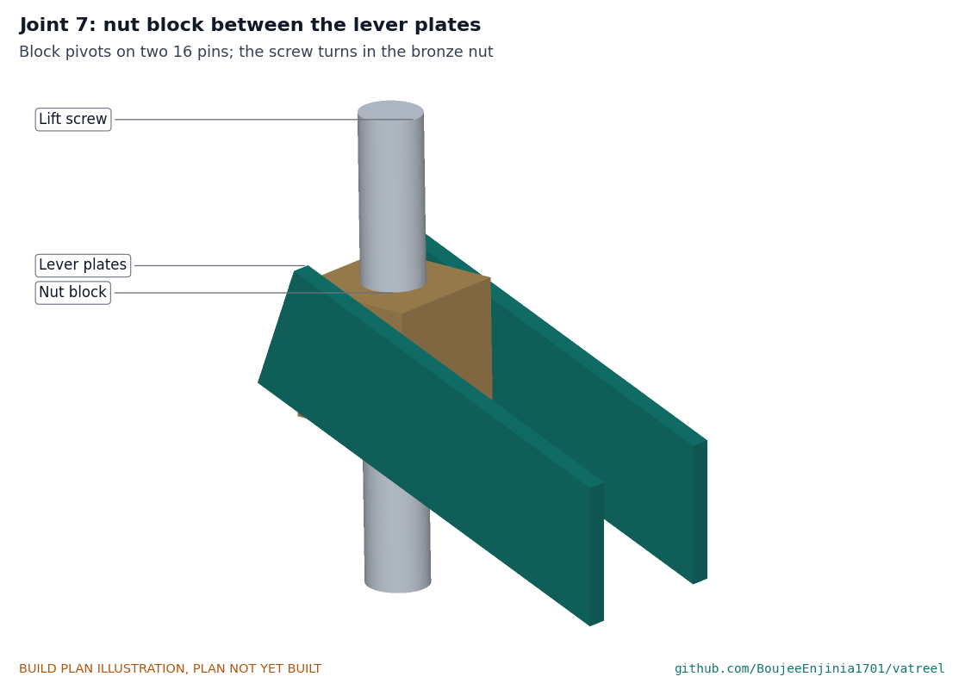
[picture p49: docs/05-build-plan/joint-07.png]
Figure 27. Joint 7: nut block between the lever plates


*Figure 27. Joint 7. The nut block pivots between the lever plates; the screw turns in the bronze nut.*

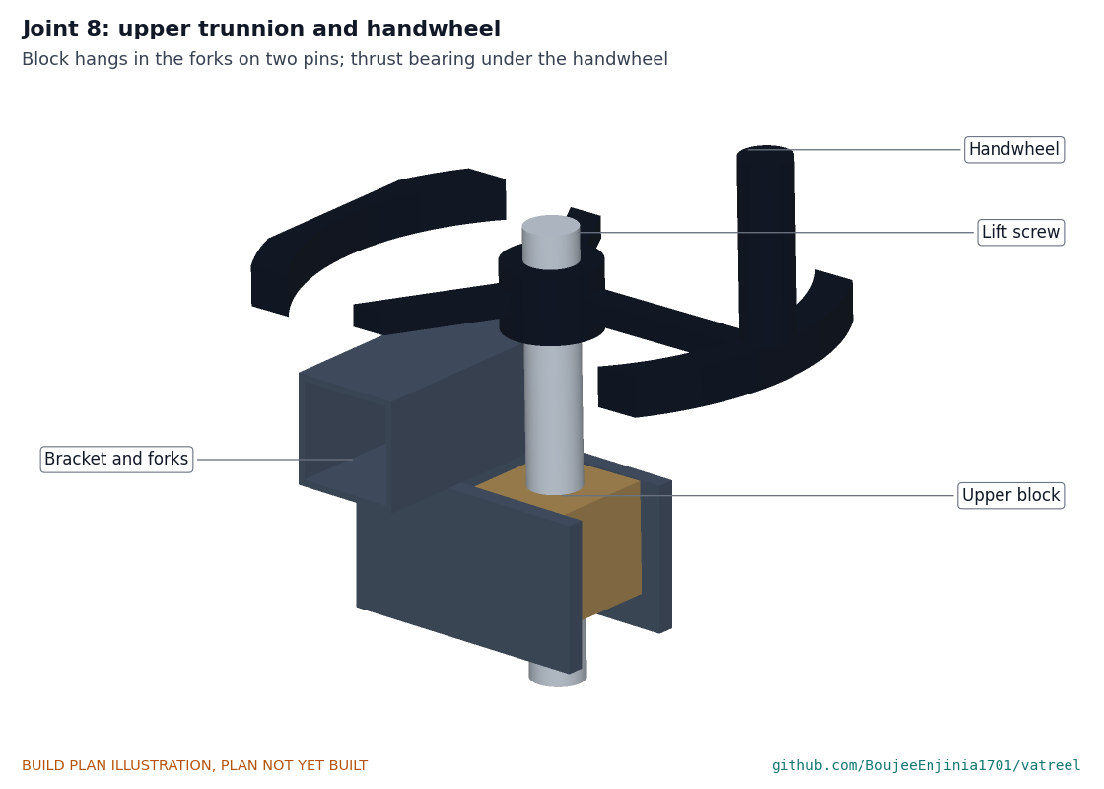
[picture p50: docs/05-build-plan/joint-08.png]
Figure 28. Joint 8: upper trunnion and handwheel


*Figure 28. Joint 8. The upper block hangs in the forks on two pins; the thrust bearing sits under the handwheel.*

### 3.18 Drive parts, bushes and fixings (bought)

**What to buy.** ISO 606 08B-1 plate sprockets with hubs: 15 teeth bored 30 and 30 teeth bored 40 (plated steel, inside the tower); 17 teeth bored 40 and 51 teeth bored 48.3 (304 stainless, on the arm). Chain 1, plated steel, about 1.9 m; chain 2, 304 stainless, about 2.3 m, with connecting links. Four flanged UHMW-PE bushes for the tower (two 40 bore, two 30 bore); UHMW-PE bushes for the torque tube (40 x 70 and 60.3 x 70); two split glass-filled PTFE bushes 48.3 x 60 x 40 for the axle. Two split shaft collars (68 and 90 outside, 60.3 bore). Eighteen 316 snap hooks. A4 bolts, roll pins, R-clips. Six EPDM pads. A 3.6 m steel pipe 33.7 x 3.2 (the assembly bar).

**What to do to them.** Drill each sprocket hub 6 for its roll pin together with its shaft (section 3.3). Cut chains to length when fitted. Ream bushes lightly if a shaft does not turn by hand.

## 4. Putting it together

Two people, working only from the rims. Fit over an empty pit or a water-filled test tank first.

### Step 1: base frame on the near rim

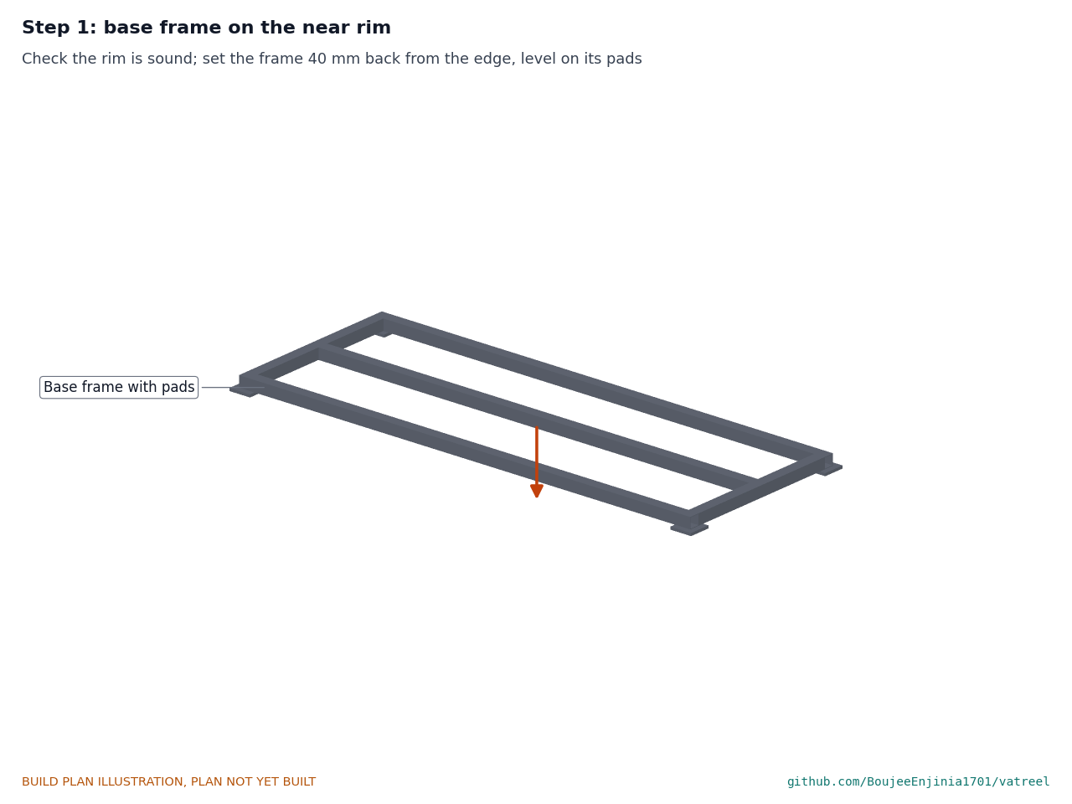
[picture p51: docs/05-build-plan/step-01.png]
Step 1


Check the rim is sound and level. Set the frame 40 back from the pit edge, its left end 550 past the pivot position (the pivot line is 350 in from the pit's end wall). Pack pads to level it.

### Step 2: tower and braces

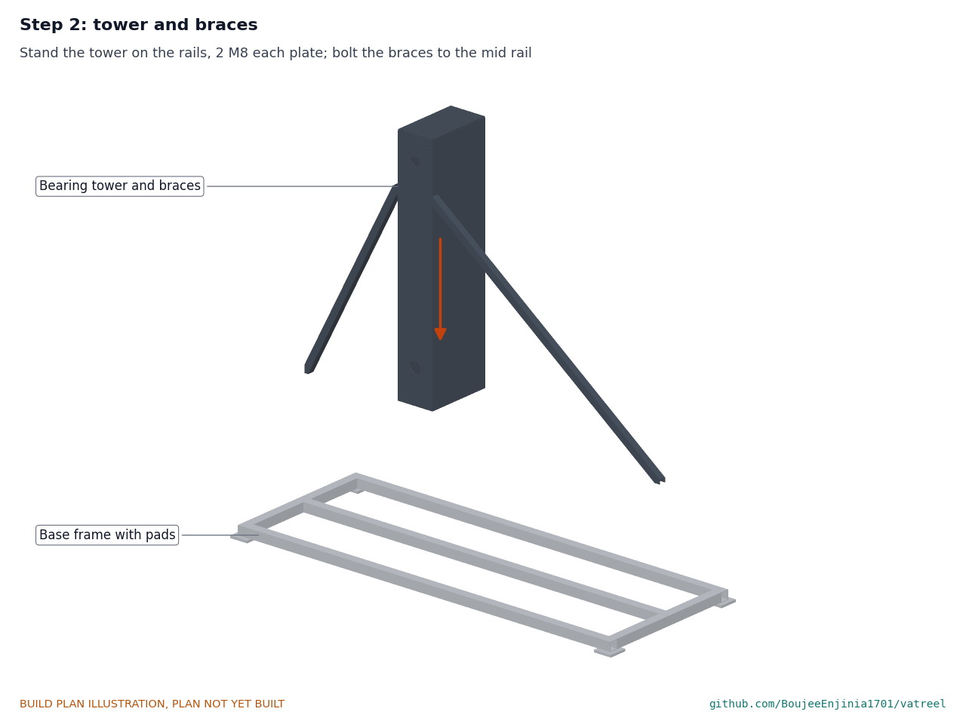
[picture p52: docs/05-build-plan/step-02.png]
Step 2


Stand the tower on the front and mid rails, two M8 per plate. Bolt the braces from the tower sides to the mid rail ends.

### Step 3: shafts, bushes, sprockets and chain 1

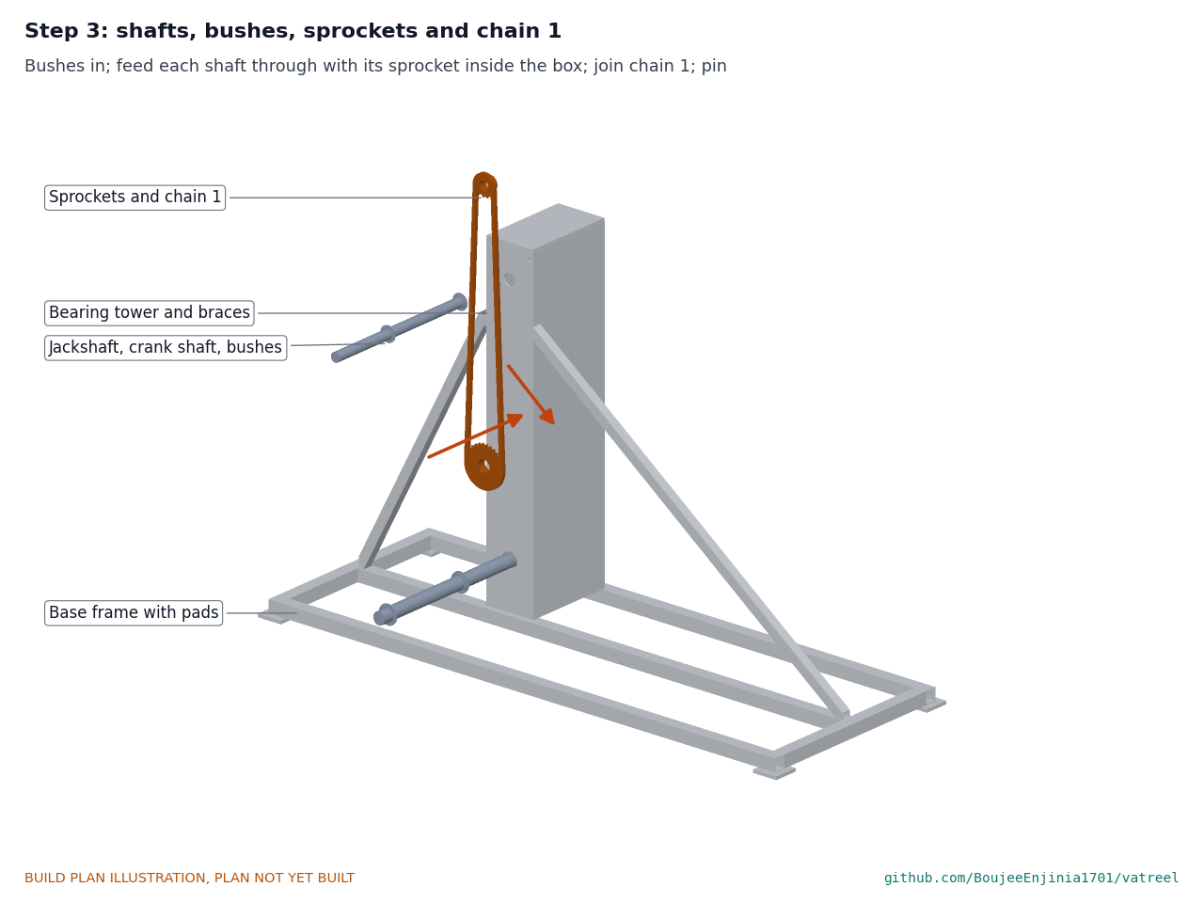
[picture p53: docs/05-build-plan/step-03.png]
Step 3


Push the four flanged bushes into the tower plates. Feed the jackshaft in from the back, threading the large chain 1 sprocket onto it inside the box; feed the crank shaft the same way with the small sprocket. Join chain 1 round both; pin both sprockets. Slide the chain 2 sprocket onto the jackshaft tip and pin it.

### Step 4: ratchet, pawl, cover and crank

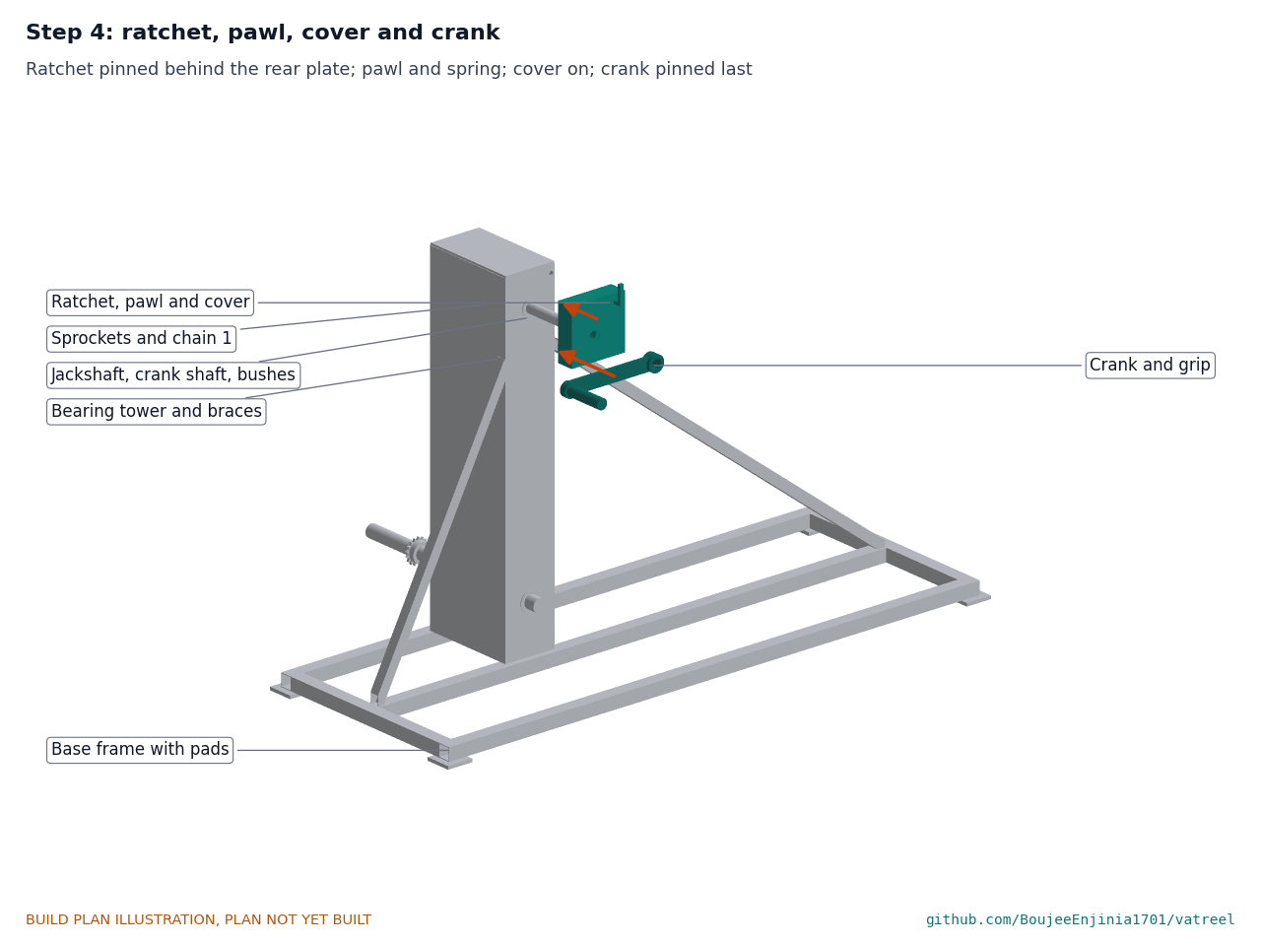
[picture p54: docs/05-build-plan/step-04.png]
Step 4


Pin the ratchet wheel on the crank shaft just behind the rear plate. Fit the pawl pin through the rear plate with its spring; bolt on the cover; fit the release lever. Pin the crank on last.

### Step 5: splash shield

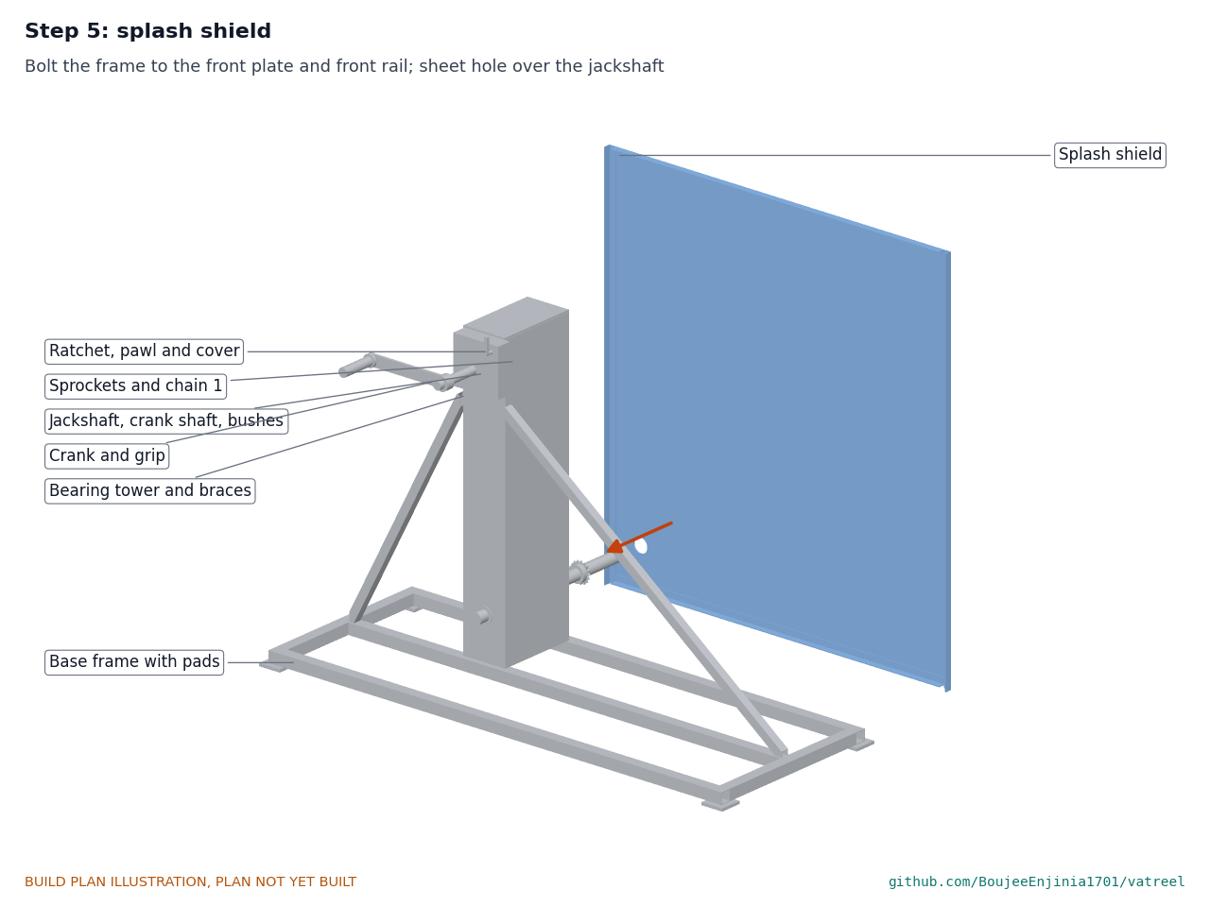
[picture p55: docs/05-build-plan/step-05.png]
Step 5


Bolt the shield frame to the front tower plate and to the front rail; the sheet's hole goes over the jackshaft.

### Step 6: far stand on the far rim

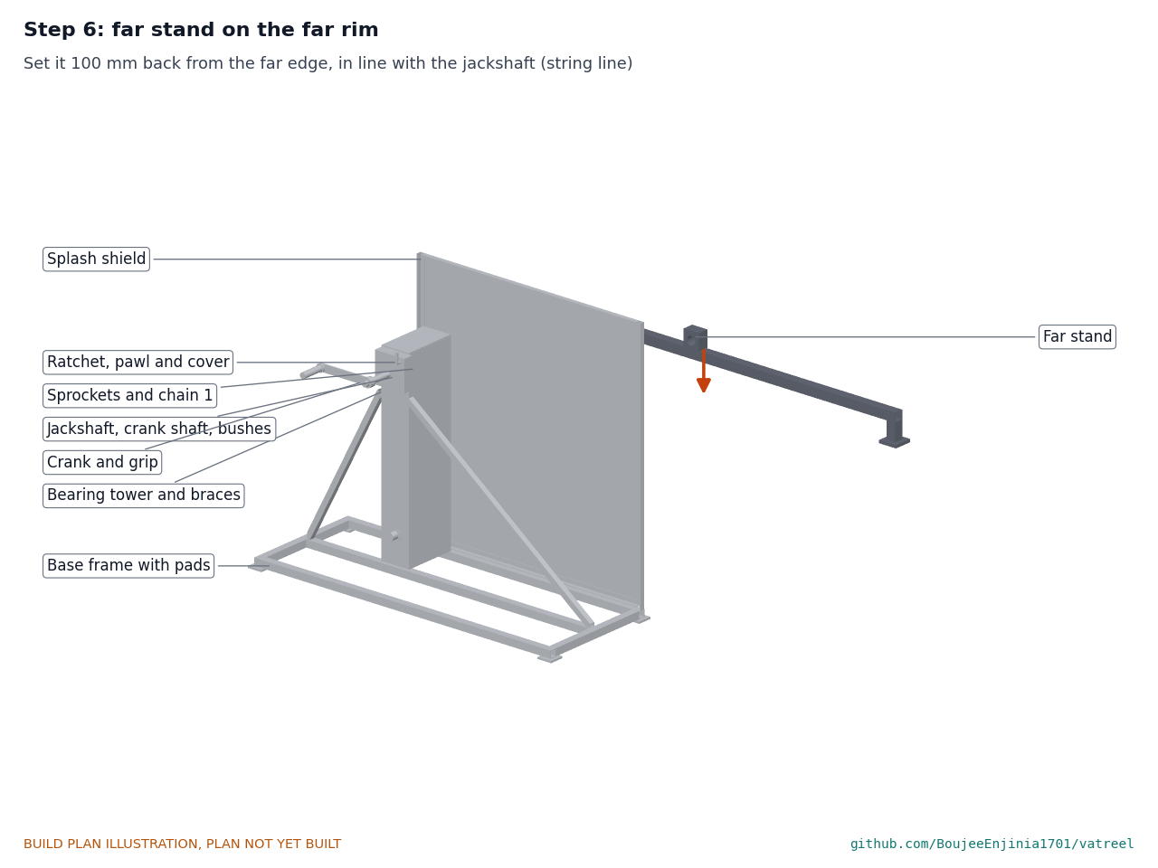
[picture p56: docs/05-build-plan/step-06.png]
Step 6


Stretch a string from the jackshaft square across the pit; set the far stand on the far rim 100 back from the edge with its clamp on the string line. Open the clamp cap.

### Step 7: pivot tube and arm frame onto the jackshaft

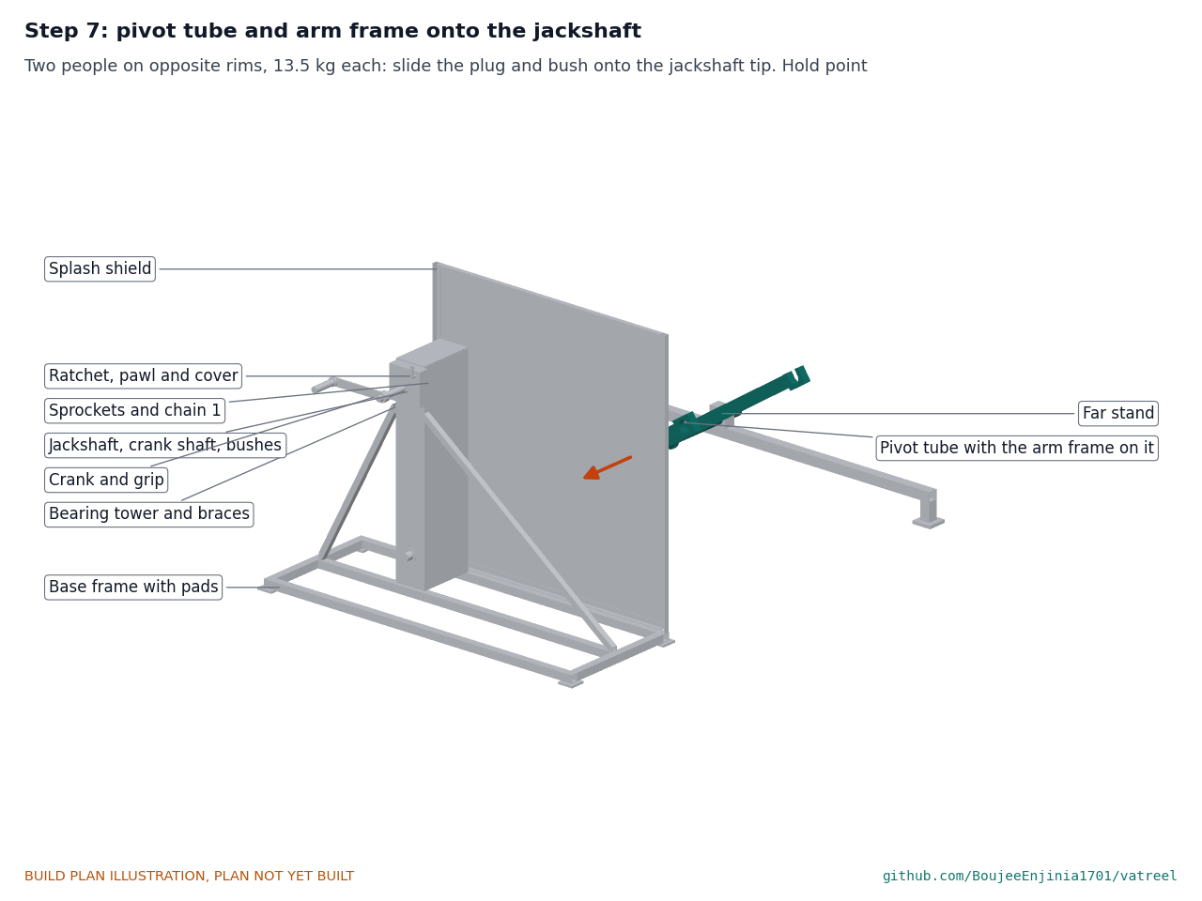
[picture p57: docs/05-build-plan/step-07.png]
Step 7


Off the pit, slide the inner collar onto the pivot tube, then the arm frame (its far bush onto the tube from the far end), then the outer collar; tighten both collars. Two people, one on each rim, carry the tube and frame across (13.5 kg each) with the arms tied up to the tube, and slide the frame's near bush and the tube's plug onto the jackshaft tip. **Hold point:** the arms stay tied until the lift screw is fitted.

### Step 8: extension tube and far clamp

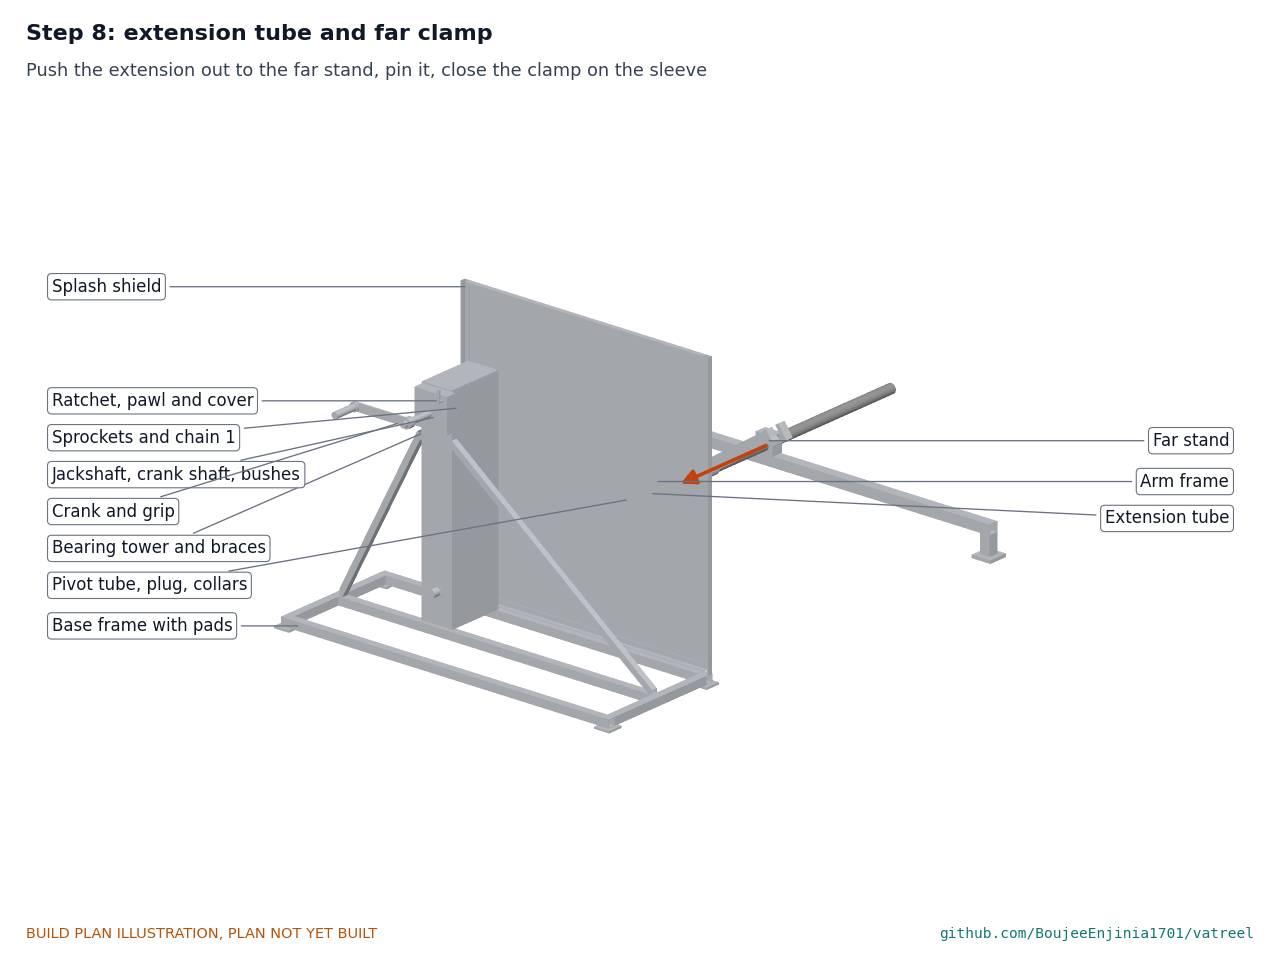
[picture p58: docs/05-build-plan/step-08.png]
Step 8


For pits wider than 1.22 m, push the extension out of the pivot tube to the far stand and put the lynch pin through the hole marked for this pit. Close the clamp cap on the tube (with the split sleeve on the extension).

### Step 9: bracket and lift screw

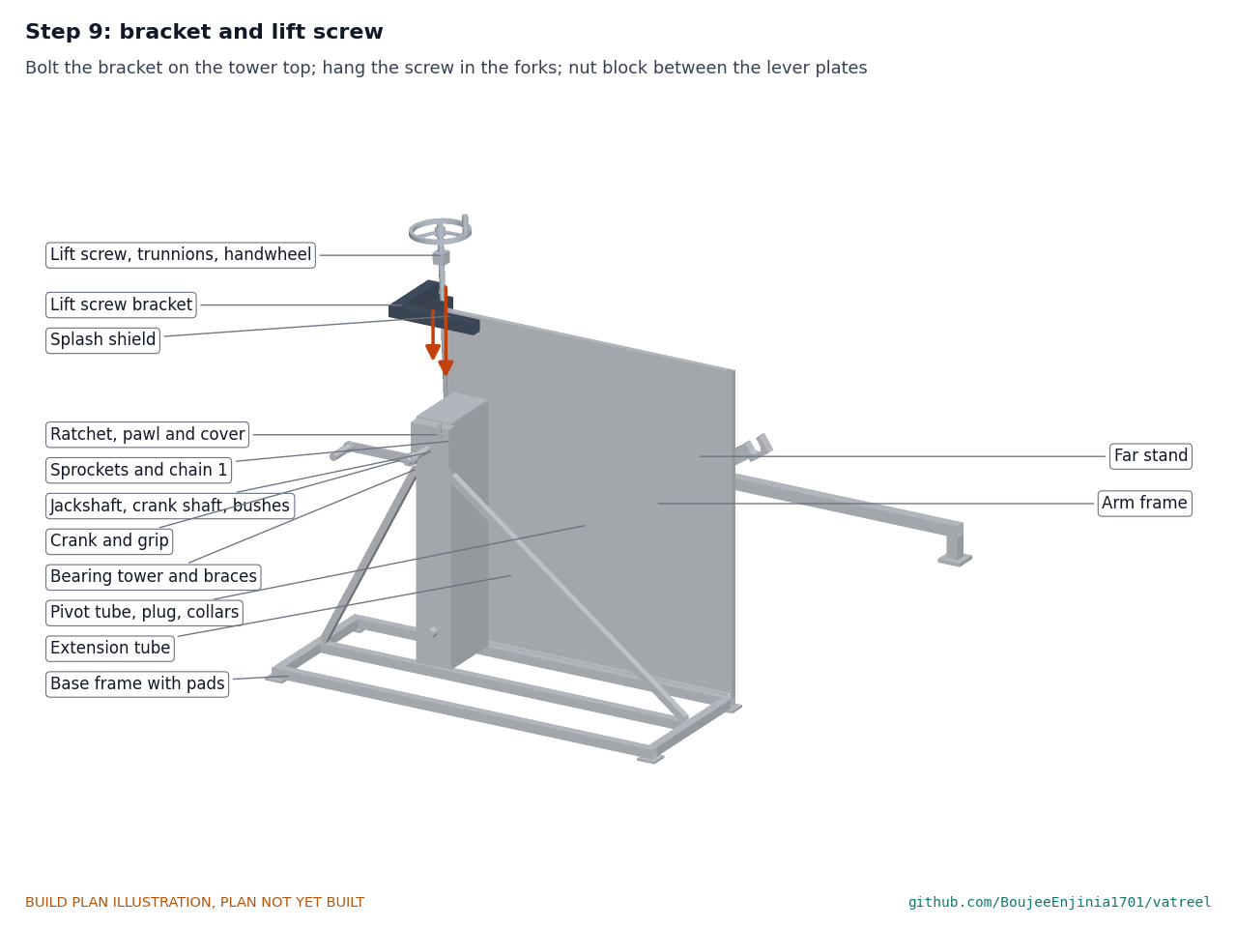
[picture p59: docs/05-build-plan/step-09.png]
Step 9


Bolt the bracket on the tower top. Hang the upper trunnion in the forks; put the nut block between the lever plates with its pins. Untie the arms and wind the handwheel until the arms are fully raised.

### Step 10: reel onto the raised arms

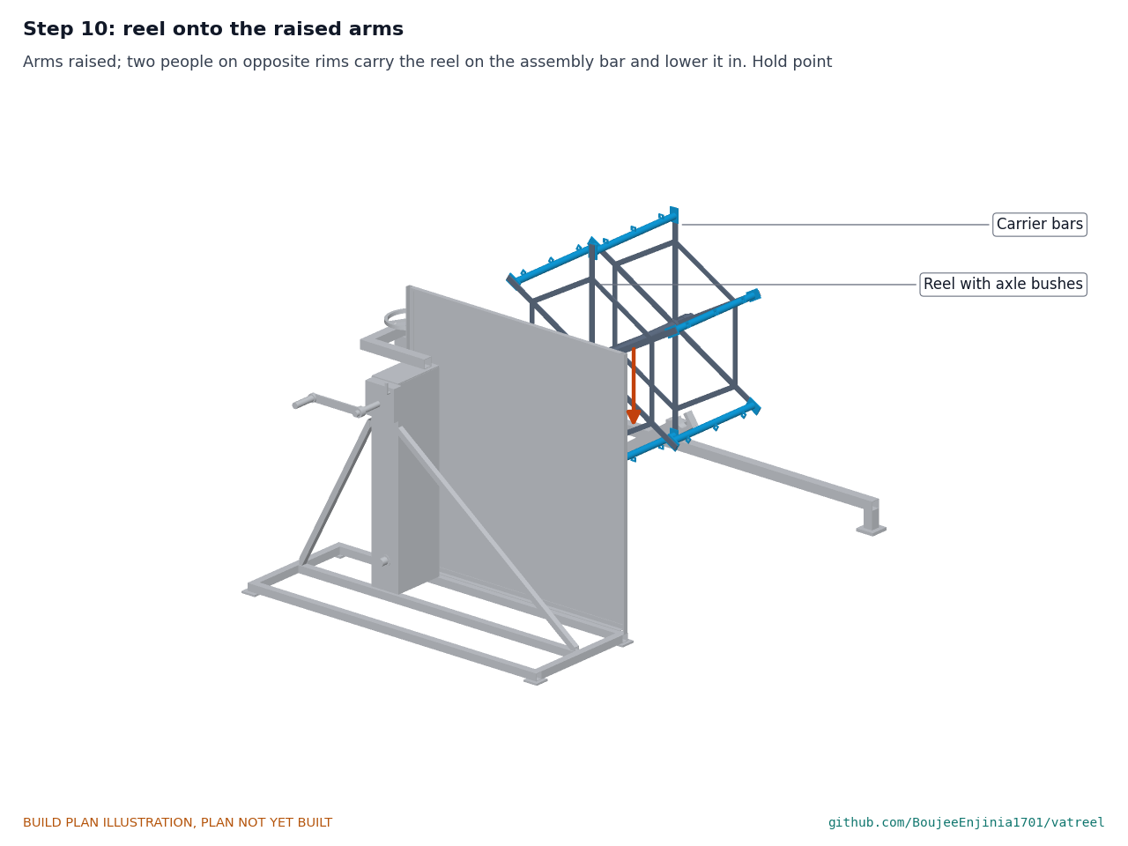
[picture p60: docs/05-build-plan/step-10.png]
Step 10


Push the assembly bar through the reel's hollow axle. One person on each rim lifts the bar (about 15 kg each) and lowers the axle into the near split block (cap off) and the far saddle (keeper open). **Hold point:** both ends seated before anyone lets go of the bar.

### Step 11: keeper, near cap, axle sprocket and chain 2

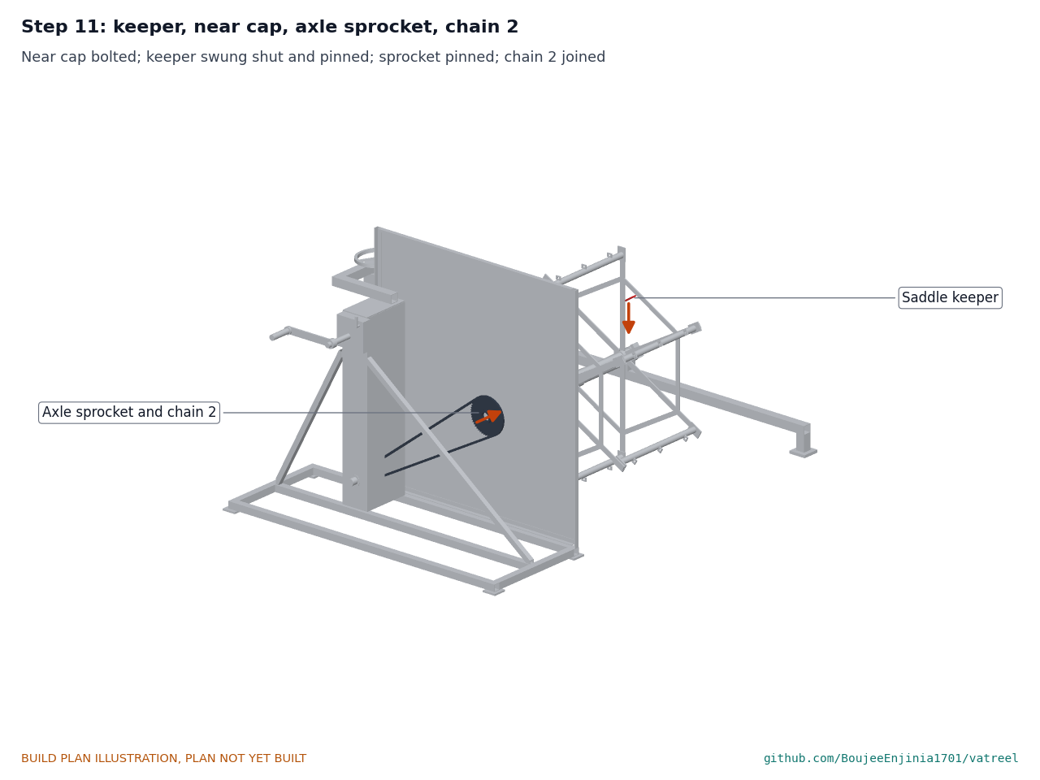
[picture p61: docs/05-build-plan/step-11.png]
Step 11


Close the keeper over the far end of the axle with the loading hook and pin it from the far rim. Bolt the near cap. Pin the axle sprocket on the axle's near end; join chain 2 round both chain 2 sprockets. Withdraw the assembly bar.

### Step 12: chain 2 guard

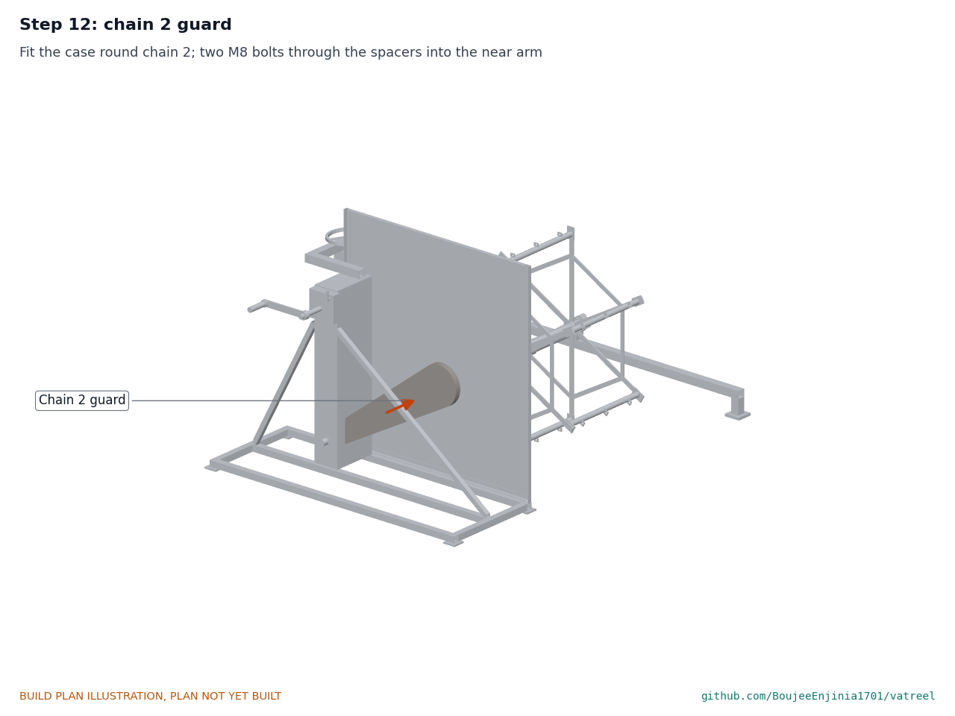
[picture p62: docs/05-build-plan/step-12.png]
Step 12


Fit the case round chain 2 (open the rim strip joint if it is bolted) and fix it to the near arm with two M8 through the spacers.

### Step 13: lower to the working depth; hooks on the base

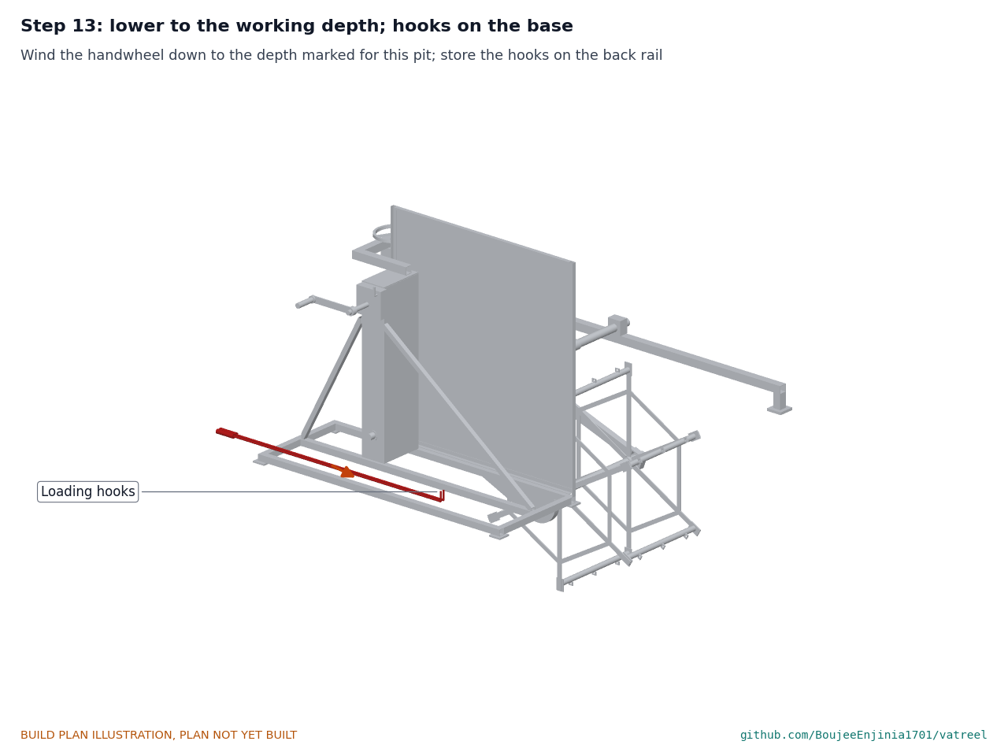
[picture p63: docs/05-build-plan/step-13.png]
Step 13


Wind the handwheel down to the depth marked for this pit. Hang the snap hooks on the carrier bar eyes and store the loading hooks on the back rail.

## 5. First checks

These are listed for the TRL 4 build; a test report records them.

*Table 2. First checks.*

| Check | Requirement | How | Pass when |
| --- | --- | --- | --- |
| Fit across the pit | R3 | Set up over pits (or frames) 1.0 and 2.5 m wide | Both stands flat on the rims, tube pinned with 250 overlap |
| Depth range | R4 | Measure the lowest bar below the rim at the handwheel's ends of travel | 300 or less and 1,000 or more |
| Lift | R11 | Wind fully up; let go of the handwheel loaded with 1.5 x | Every bar above the rim; no creep in 10 min |
| Crank force | R2 | Spring balance on the grip, 25 kg of wet sandbags on one bar, over water | 100 N or less |
| Holding | R5 | 1.5 x load on one bar, crank released | No slip at the ratchet |
| Hands out of liquor | R1 | Load and unload a batch with the hooks only | No hand below the rim |
| Splash | R9 | Indicator paper on the operator's apron, normal cranking | No marks |
| Guarding | R12 | Competent person checks every opening near the chains, ratchet and screw | Meets ISO 13857 |
| Mass and setup | R8 | Weigh each module; time a two-person setup | Recorded against the targets |

## 6. Safety stops

Work stops at each point below until what is listed is true.

1. **Before placing anything on a rim:** the rim is checked sound and dry, and the floor round it is clear. Both people wear gloves, eye protection and boots.
2. **Before any lift over the pit (steps 7 and 10):** two people, one on each rim, have agreed the lift; nobody stands on boards or the frame over the pit; the pit is empty or the liquor is cold.
3. **Before letting go of the arm frame (step 9):** the lift screw is fitted and the nut block pinned; until then the arms stay tied up.
4. **Before letting go of the reel (step 10):** the axle is seated in both bearings; then the keeper is pinned and the cap bolted.
5. **Before the first turn of the crank:** the chain 1 box, the ratchet cover and the chain 2 case are closed; the shield is on; nobody is on the far rim within reach of the reel.
6. **Before the first load:** the reel has turned ten times empty and the ratchet holds; the first loads are water and sandbags in a test tank, not liquor.
7. **Before working in liquor:** the R5 holding check and the R12 guarding check are passed (TRL 4).
8. **Before a hot bath (above 60 °C):** two people are present; the shield is on; loads go on and off only at the top of the reel with the hooks.
9. **Before reaching toward the reel for any reason:** the reel is stopped, the ratchet is engaged and the arms are wound up.

## 7. Tools, skills and workspace

- **Tools:** metal-cutting saw or cut-off saw, angle grinder with cutting and flap discs, pillar drill and hand drill with 6 to 25 mm bits and a 50 hole saw, taps M6 to M16, files, vice, spanners, TIG or stick welder for stainless with 316L filler, pickling paste, spring balance, tape, square and string line.
- **Skills:** stainless welding with clean, full fillets; drilling holes in line through two parts; reading the making sketches.
- **Workspace:** a flat floor for the jigs; ventilation or extraction for stainless weld fume; a water-filled test tank or empty pit for first assembly.

## 8. Where the numbers come from

- Model: `cad/src/model.py` (fit checks: `python cad/src/model.py --check`)
- General arrangement: `cad/drawings/VTR-DWG-001`; making sketches `cad/drawings/VTR-DWG-101` to `VTR-DWG-116`
- Calculation note: `docs/04-calcs/01-sizing.md` (VTR-CAL-001) and `docs/04-calcs/sizing.py`
- Bill of materials: `bom/bom.csv`
- Pictures: `cad/src/build_plan_media.py`
- Decisions: `docs/decisions/0001-trl2-review-decisions.md`, `docs/decisions/0002-design-for-construction.md`

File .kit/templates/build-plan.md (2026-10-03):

---
doc_id: PRJ-BLD-001
title: Project prototype build plan
project: Project name
doc_type: Build plan
version: "0.1"
status: Draft
date: YYYY-MM-DD
author: Amish Chadha
license: CERN-OHL-S-2.0
revisions:
  - version: "0.1"
    date: YYYY-MM-DD
    author: Amish Chadha
    change: First build plan; design made constructable
---

# Project prototype build plan

**Plan, not yet built.** How to build the first proof-of-concept prototype, component by component. Building and testing to it is TRL 4 work. Decisions still to be made are kept in the design decisions register (`docs/06-design-decisions.md`), not here.

## 1. What you are building

Every component, pulled apart and numbered in build order

One short paragraph: what the prototype is, how many components, which are made and which are bought, and the main ways they are made.

## 2. What changed to make it buildable

| Component | The concept had | The buildable design has | Why |
| --- | --- | --- | --- |

## 3. Making the components

### 3.1 Component name

Making sketch

**What it is and what it is made from.**

**How to make it.**

1. Mark out ...
2. Cut ...

**How it fits the parts next to it.**

Close-up of the joint

**Check before moving on.**

## 4. Putting it together

### Step 1: ...

Step 1

## 5. First checks

| Check | Requirement | How | Pass when |
| --- | --- | --- | --- |

## 6. Safety stops

## 7. Tools, skills and workspace

## 8. Where the numbers come from

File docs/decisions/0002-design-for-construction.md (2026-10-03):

---
doc_id: VTR-DDR-002
title: VatReel design for construction
project: VatReel
doc_type: Design decision record
version: "0.1"
status: Draft
date: '2026-10-03'
author: Amish Chadha
license: CERN-OHL-S-2.0
revisions:
- version: "0.1"
  date: '2026-10-03'
  author: Amish Chadha
  change: Constructability review of the TRL 3 model; every change made under Amish's 2026-10-03 pre-approval
---

# 0002: Design for construction

- **Date:** 2026-10-03
- **Status:** accepted
- **Decided by:** Amish Chadha, by pre-approval: "start with the first 14 repos from the list of 29 projects. I pre-approve the batch runs along with any recommendations you come up with. I also accept any cost overruns or variations from the assumed scope cost."

## Context

Writing the prototype build plan (VTR-BLD-001) means every part must be makeable by the stated process and must fit and fasten to its neighbours (STANDARDS section 18; Amish, 2026-09-30: "fix the design assumptions to match and be physically feasible"). The TRL 3 model was checked with build123d: no two components overlap, every joint face touches (a gap of 0.6 mm at most, a sliding fit), and nothing collides with the frame or the pit walls with the arms lifted, at the shallowest and at the deepest setting (`python cad/src/model.py --check`, 45 components). The changes below were needed to get there. None changes what VatReel does, its pitch or its safety case, except to make guarding more complete.

## Decision

*Table 1. Changes from the concept to the constructable design.*

| # | Component | The concept had | The constructable design has | Why |
| --- | --- | --- | --- | --- |
| 1 | Arm frame | Two arms joined by a small tie tube 180 mm out from the pivot | Both arms welded to a 76.1 x 3 mm torque tube round the pivot line | The lift screw acts on the near arm only; the tie would have carried the far arm's moment in bending at about 280 MPa. The torque tube carries it in torsion at 29 MPa |
| 2 | Sprockets | 12 teeth on the 30 and 40 mm shafts | 15 and 30 teeth (chain 1), 17 and 51 teeth (chain 2); ratio kept at 6 to 1 | A 12-tooth 08B sprocket cannot be bored to 30 or 40 mm |
| 3 | Chain 2 guard | A flat plate on the wall side | A closed case of 1.5 mm sheet round the chain, on two spacers | The plate left the chain open at its edges (R12) |
| 4 | Bearing tower | Open at the bottom; ratchet exposed | Bottom sheet closes the chain box; a cover over the ratchet and pawl with the release lever outside | Close the last openings to chain 1 and the pawl (R12) |
| 5 | Far bearing | A split block with a bolted cap | An open-topped saddle with a keeper that swings shut | The far bearing is 0.9 m into the pit; the reel must drop in without anyone reaching there |
| 6 | Near bearing | Solid housing | Split block with a bolted cap | The reel is fitted from above, not slid along its axle |
| 7 | Pivot tube support | A bracket from the stand round the chain 2 sprocket | A plug in the tube's near end riding on the jackshaft tip | No bracket can pass the sprocket and the swinging arm; the jackshaft carries it at 39 MPa |
| 8 | Arm frame location | Not set | An inner collar (inside the torque tube) and an outer collar on the pivot tube | Holds the frame along the tube so chain 2 stays in line |
| 9 | Pivot tube reach | One telescopic tube | Pivot tube 1.2 m plus a 1.55 m extension pinned inside it at 100 mm steps; far stand clamps on either through a split sleeve | Spans 1.0 to 2.52 m with no tube end standing out more than about 150 mm |
| 10 | Splash shield | 1.12 m wide, from 260 mm above the rim | 1.32 m wide, from 60 mm, with a hole for the jackshaft | Sight lines from the reel to the operator's eye missed the narrower shield (R9) |
| 11 | Base frame | 1.55 m long | 1.75 m long | Carries the wider shield |
| 12 | Tower braces | Welded to the tower | Bolted, and lowered to clear the ratchet cover | Keeps the tower at 23.2 kg to carry; the braces clashed with the cover |
| 13 | Spiders | Spokes butted to the axle | Spokes on a 40 mm hub sleeve, hexagon ties between them | A joint that can be jigged and welded square |
| 14 | Carrier bars | Bars welded to the spokes | Bars with end plates bolted to the spoke tips; eye tabs for snap hooks | Bars can be replaced; the reel is carried as one piece |
| 15 | Axle sprocket | Hub toward the arm | Hub on the wall side | The hub hit the guard case's inner plate |
| 16 | Loading hooks | Not sized | 1.5 m hooks stored on the base frame's back rail | They must reach the far end of a carrier bar from the near rim |
| 17 | Reel installation | Not worked out | A 3.6 m assembly bar through the hollow axle; two people on opposite rims carry the reel onto the raised arms | No one reaches 0.9 m over the pit |
| 18 | Assembly order | Not worked out | The thirteen steps of VTR-BLD-001 section 4, set by what fits past what | The arm frame must be on the pivot tube before the tube goes onto the jackshaft |

## Consequences

- `cad/src/model.py` holds every change; STEP and STL are regenerated; the general arrangement VTR-DWG-001 moves to Rev P2; the concept media and the build plan pictures are regenerated from the model.
- The parts cost moves to USD 1,437 against the USD 1,500 value-engineering target (USD 63 under). The guard case, cover and wider shield added about USD 40; the BOM lists every part.
- VTR-CAL-001 v0.2 reruns every check on the constructable design; all stresses stay within yield / 1.5 at the proof load.
- R8 is not met as written (two two-person modules, setup about 29 minutes); this is recorded as a decided limit in VTR-DEC-001.
- `design_state: constructable` is set in `project.yaml`.

> **Safety:** Changes 3, 4, 5 and 10 improve guarding and splash protection. The plan's safety stops (VTR-BLD-001 section 6) apply to every step.

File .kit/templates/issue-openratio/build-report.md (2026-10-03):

---
name: Build report
about: Tell us what happened when you built, printed or tested part of this design
title: "Build report: "
labels: build-report
---

This is a research and educational prototype, not a medical device. It is a TRL 3 concept and is not released for fabrication. If you build any part of it, you do so at your own risk. Reports help everyone.

**What you built** (part, sub-assembly or test)

**Materials, tools and settings**

**What worked**

**What did not work, with photos or measurements if you have them**

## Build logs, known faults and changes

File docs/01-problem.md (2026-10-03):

---
doc_id: VTR-PRB-001
title: VatReel problem statement
project: VatReel
doc_type: Problem statement
version: "0.2"
status: Draft
date: '2026-10-03'
author: Amish Chadha
license: CERN-OHL-S-2.0
revisions:
- version: "0.1"
  date: '2026-09-30'
  author: Amish Chadha
  change: Initial scaffold
- version: "0.2"
  date: '2026-10-03'
  author: Amish Chadha
  change: TRL 2 and 3 update; pit length and liquor level added to the environment; first co-design candidate; questions for the site survey
---

# VatReel problem statement

Pit and vat processes still depend on people moving wet, heavy material through chemical baths by hand. The simplest engineering control, keeping the body out of the liquor, is missing in the workshops that need it most.

## The problem

Tannery liquors include lime, sulphides, acids and chromium salts; dye baths can be hot and contain sensitising dyes. Studies in Kanpur and Sialkot link skin disease and raised chromium levels to this work, and the risk rises with the degree of skin contact ([Kashyap et al., 2021](https://pmc.ncbi.nlm.nih.gov/articles/PMC8530047); [Khan et al., 2013](https://journals.sagepub.com/doi/10.1177/0748233711430974)). Gloves and boots help, but workers in Hazaribagh reported that liquor still reaches the skin when they climb into pits ([HRW, 2012](https://www.hrw.org/report/2012/10/09/toxic-tanneries/health-repercussions-bangladeshs-hazaribagh-leather)).

Mechanised answers exist. The winch dyeing machine, one of the oldest forms of dyeing machine, pulls cloth over a reel through the bath ([Wikipedia](https://en.wikipedia.org/wiki/Winch_dyeing_machine)), and tanneries use powered paddlewheels and drums ([Exeter Machine](https://exetermachineco.com/machines/)). These are fixed, powered and built for a factory floor. Small workshops that work in pits have no portable, hand-powered way to move a load through the bath, so they use their hands.

## Users and context

| User | Need | Context |
| --- | --- | --- |
| Pit and vat workers | Move hides or yarn through the liquor without putting hands, arms or legs into it | Open pits and vats in small tanneries and dye yards, often wet floors and poor lighting |
| Workshop owners and cooperatives | A control they can afford, build locally and fit over the pits they already have | Low capital, no spare power supply, pits of mixed sizes |
| Local fabricators | Drawings and a cut list that use stock sections and hand tools | Small metal workshops near tannery or craft clusters |
| NGOs, unions and auditors | A documented engineering control to recommend to small suppliers | Worker safety programmes in leather and textile supply chains |

## Operating environment

- Set across open pits or vats about 1.0 to 2.5 m (3 to 8 ft) wide and at least 1.9 m (6.2 ft) long; exact range to be confirmed by site survey.
- Pits with the rim level with the floor and the liquor about 150 mm (6 in) below the rim (assumed).
- Liquors from strongly alkaline (liming) to acidic (pickling), with chromium salts, sulphides and dyes.
- Dye baths up to about 98 °C (208 °F), the top of the range used in winch dyeing ([Wikipedia](https://en.wikipedia.org/wiki/Winch_dyeing_machine)).
- Wet, slippery floors; outdoor or open-sided sheds; hot and humid climates.
- No reliable mains power assumed.

## Constraints

- Prototype parts budget: USD 1,500 or less.
- Hand powered only; no motor in the base design.
- Buildable with hand tools and stock steel or stainless sections; no casting or machining beyond drilling and cutting.
- Each module light enough for two people to carry (target 25 kg (55 lb) or less, estimate).
- Fits existing pits without civil works.
- Open design: hardware under CERN-OHL-S-2.0, any software or calculators under MIT.

## Out of scope

- Motorised drives, drums and automatic dosing.
- Effluent treatment and chemical substitution (important, but separate problems).
- Fixed plant for large tanneries.
- Personal protective equipment design.

## Prior work

| Prior work | What it does | Gap for these users | Source |
| --- | --- | --- | --- |
| Winch (beck) dyeing machine | Reel that pulls cloth in rope form through a dye bath in an endless loop | Fixed, powered factory machine with its own tank; not portable and not for hides or pits | [link](https://en.wikipedia.org/wiki/Winch_dyeing_machine) |
| US3513672A, paddle dyeing machine (expired) | Tilting cylindrical dye tank with an integral paddle for circulation, hydraulically powered | Powered, fixed tank; no hand operation or use over an existing pit | [link](https://patents.google.com/patent/US3513672A/en) |
| Tannery paddlewheels and drums (for example Exeter Machine) | Wooden paddlewheels from about 1.2 by 1.2 m and drums up to about 3.7 m for processing hides | Powered plant equipment that replaces the pit rather than working over it | [link](https://exetermachineco.com/machines/) |
| Traditional pit working (Chouara, Fez) | Workers stand in the vats and slosh hides by hand and foot | The status quo: full body contact with the liquor | [link](https://www.loe.org/shows/segments.html?programID=14-P13-00044&segmentID=4) |

## Co-design

A tannery or craft-dyeing cluster association, or a worker health NGO working with one, that can give access to real pits, liquors and workers, and help test loading and cranking with the people who do the job.

First candidate to approach (decided 2026-10-03 under Amish's pre-approval, VTR-DDR-001): a worker health NGO or tannery association in the Kanpur leather cluster, India, where the skin-contact evidence above was gathered. This is a candidate, not an agreed partner.

## Questions for the site survey

These are questions about the users' pits and processes, answered with the first partner; the design decisions themselves are in VTR-DEC-001.

- Which process steps matter most for exposure (liming, pickling, tanning, dyeing), and does one reel suit all of them?
- What pit sizes and depths are typical in the first partner cluster?
- How do workers load heavy wet hides onto carriers without handling liquor-soaked leather?
- Which materials (stainless grade, HDPE, coated steel) survive both lime and acid liquors at this budget?
- Is one reel per pit practical, or should the frame move between pits?

> **Safety:** The work described here involves corrosive liquors (lime, sulphides, acids, chromium salts), hot dye baths near 98 °C (208 °F), open pit edges and wet floors. VatReel adds a hand-cranked machine with moving parts. Any site work, survey or trial follows a local risk assessment, with gloves, eye protection and boots worn throughout.

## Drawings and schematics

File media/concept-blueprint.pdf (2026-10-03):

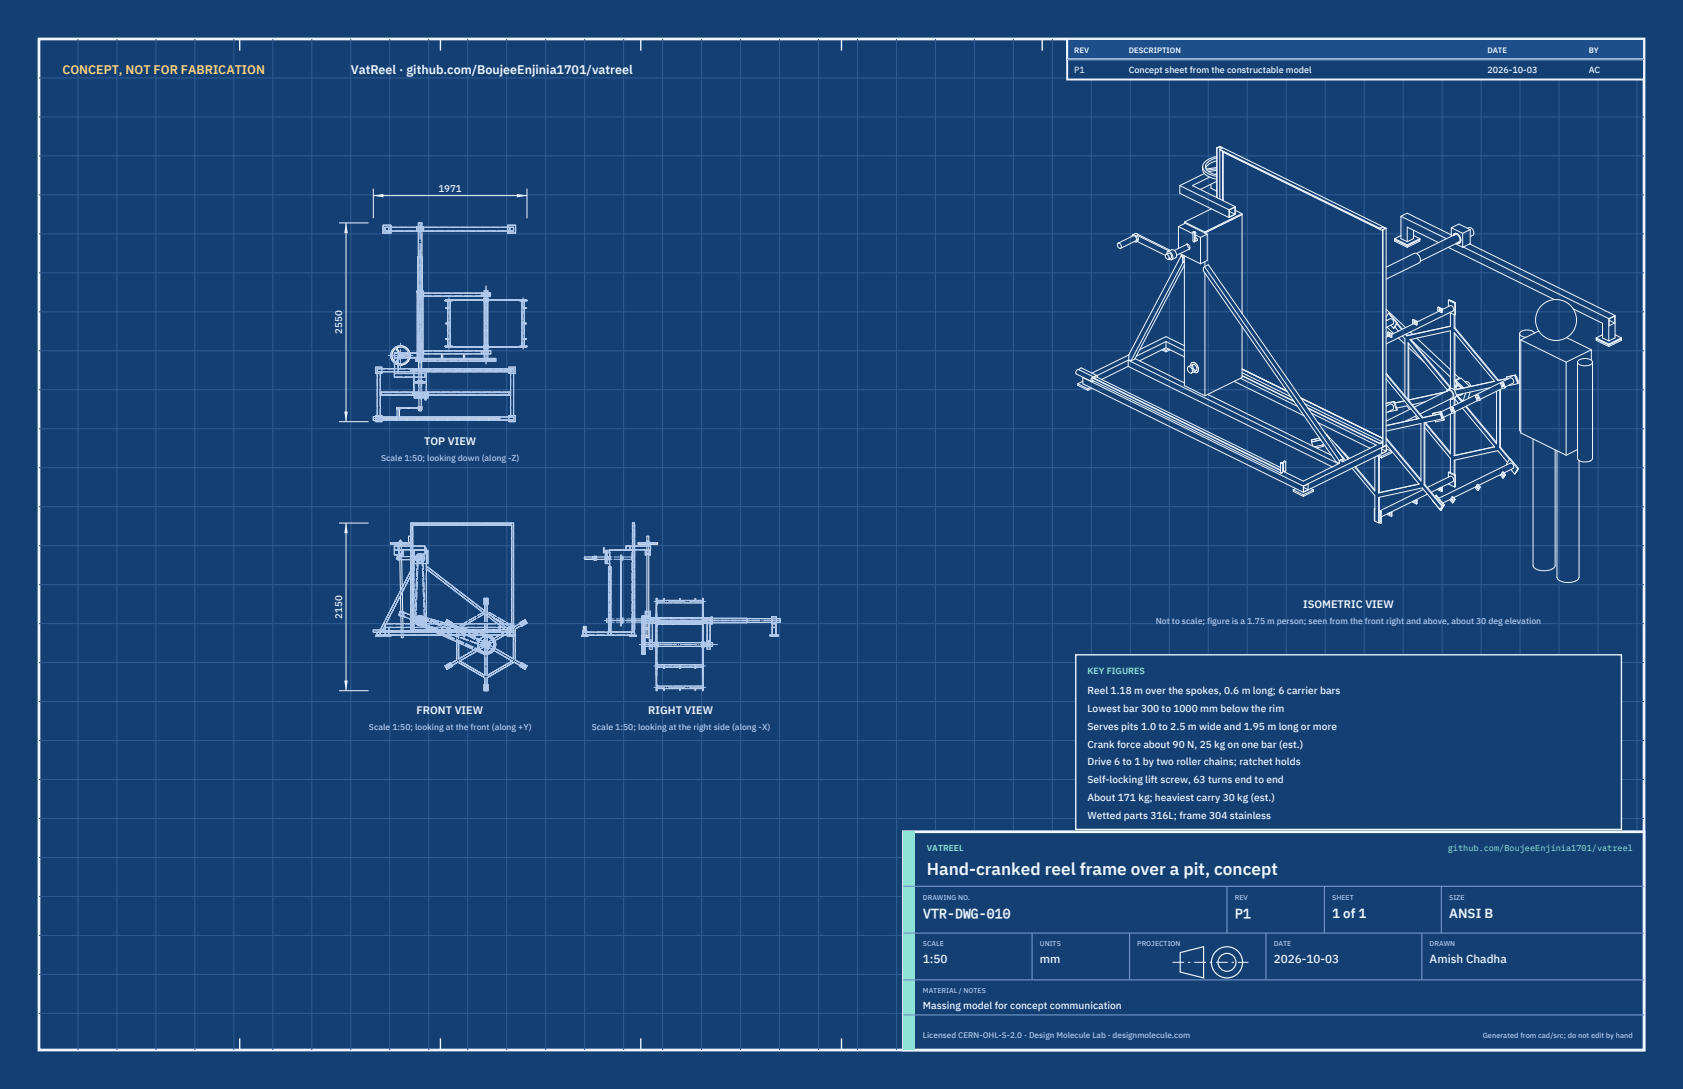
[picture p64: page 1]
CONCEPT, NOT FOR FABRICATION; VatReel · github.com/BoujeeEnjinia1701/vatreel; FRONT VIEW; TOP VIEW; RIGHT VIEW; ISOMETRIC VIEW; REV; DESCRIPTION; DATE; Concept sheet from the constructable model; VATREEL; github.com/BoujeeEnjinia1701/vatreel; DRAWING NO. VTR-DWG-010; REV P1; SHEET 1 of 1; SIZE ANSI B; SCALE 1:50; UNITS mm; PROJECTION; DRAWN Amish Chadha; Licensed CERN-OHL-S-2.0 · Design Molecule Lab · designmolecule.com; Generated from cad/src; do not edit by hand

Scale 1:50; looking down (along -Z)

Not to scale; figure is a 1.75 m person; seen from the front right and above, about 30 deg elevation

KEY FIGURES
Reel 1.18 m over the spokes, 0.6 m long; 6 carrier bars
Lowest bar 300 to 1000 mm below the rim
Serves pits 1.0 to 2.5 m wide and 1.95 m long or more
Crank force about 90 N, 25 kg on one bar (est.)
Drive 6 to 1 by two roller chains; ratchet holds
Self-locking lift screw, 63 turns end to end
About 171 kg; heaviest carry 30 kg (est.)
Wetted parts 316L; frame 304 stainless

Scale 1:50; looking at the front (along +Y)

Scale 1:50; looking at the right side (along -X)

Hand-cranked reel frame over a pit, concept

MATERIAL / NOTES
Massing model for concept communication

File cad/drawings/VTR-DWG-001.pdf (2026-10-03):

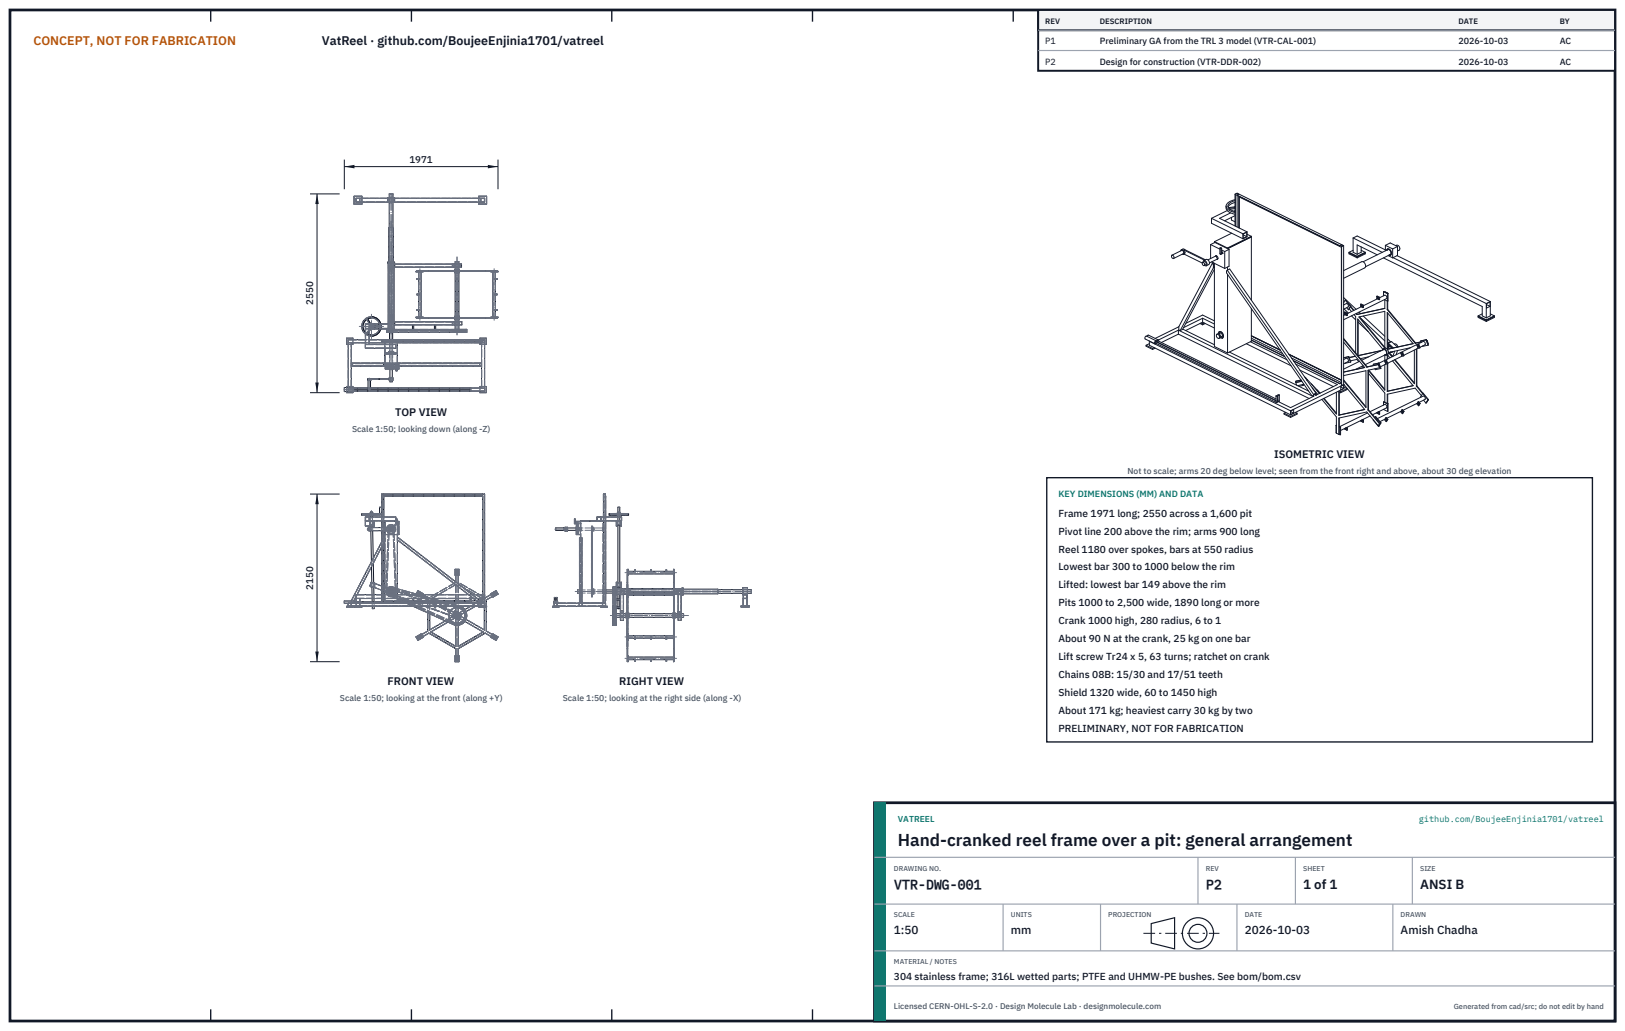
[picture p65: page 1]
CONCEPT, NOT FOR FABRICATION; VatReel · github.com/BoujeeEnjinia1701/vatreel; FRONT VIEW; TOP VIEW; RIGHT VIEW; ISOMETRIC VIEW; REV; DESCRIPTION; DATE; Preliminary GA from the TRL 3 model (VTR-CAL-001); Design for construction (VTR-DDR-002); VATREEL; github.com/BoujeeEnjinia1701/vatreel; DRAWING NO. VTR-DWG-001; REV P2; SHEET 1 of 1; SIZE ANSI B; SCALE 1:50; UNITS mm; PROJECTION; DRAWN Amish Chadha; Licensed CERN-OHL-S-2.0 · Design Molecule Lab · designmolecule.com; Generated from cad/src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

Scale 1:50; looking down (along -Z)

Not to scale; arms 20 deg below level; seen from the front right and above, about 30 deg elevation

KEY DIMENSIONS (MM) AND DATA
Frame 1971 long; 2550 across a 1,600 pit
Pivot line 200 above the rim; arms 900 long
Reel 1180 over spokes, bars at 550 radius
Lowest bar 300 to 1000 below the rim
Lifted: lowest bar 149 above the rim
Pits 1000 to 2,500 wide, 1890 long or more
Crank 1000 high, 280 radius, 6 to 1
About 90 N at the crank, 25 kg on one bar
Lift screw Tr24 x 5, 63 turns; ratchet on crank
Chains 08B: 15/30 and 17/51 teeth
Shield 1320 wide, 60 to 1450 high
About 171 kg; heaviest carry 30 kg by two
PRELIMINARY, NOT FOR FABRICATION

Scale 1:50; looking at the front (along +Y)

Scale 1:50; looking at the right side (along -X)

Hand-cranked reel frame over a pit: general arrangement

MATERIAL / NOTES
304 stainless frame; 316L wetted parts; PTFE and UHMW-PE bushes. See bom/bom.csv

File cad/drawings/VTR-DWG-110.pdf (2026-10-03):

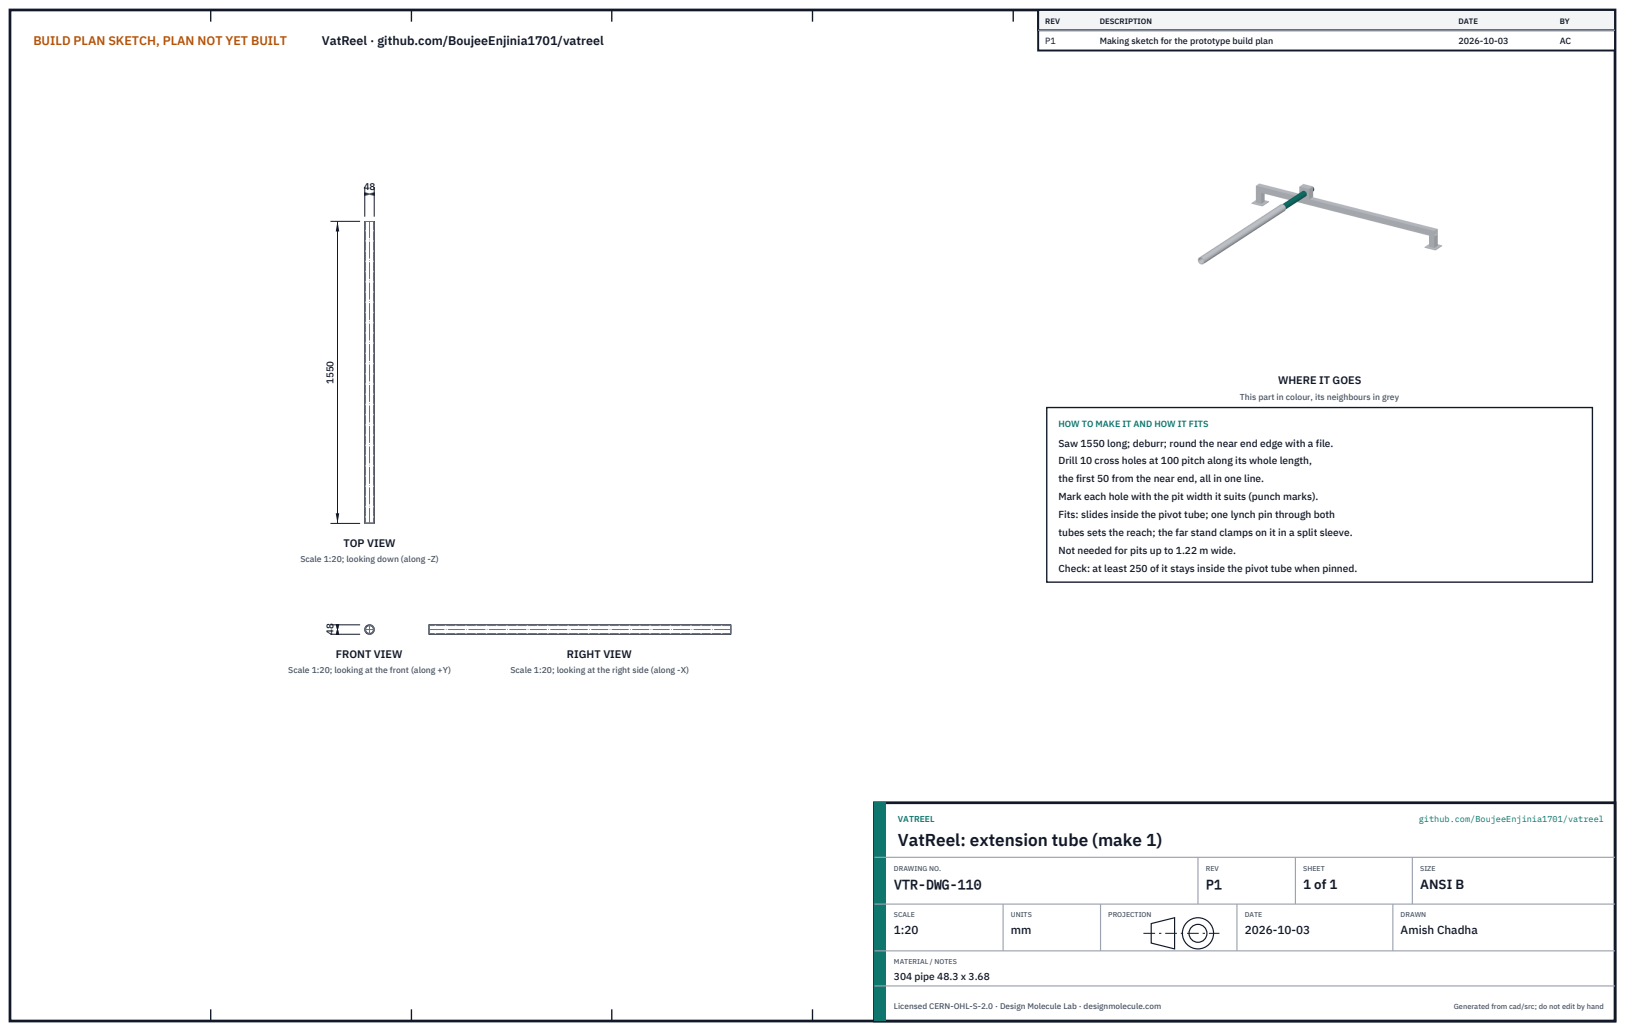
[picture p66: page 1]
BUILD PLAN SKETCH, PLAN NOT YET BUILT; VatReel · github.com/BoujeeEnjinia1701/vatreel; FRONT VIEW; TOP VIEW; RIGHT VIEW; REV; DESCRIPTION; DATE; Making sketch for the prototype build plan; VATREEL; github.com/BoujeeEnjinia1701/vatreel; DRAWING NO. VTR-DWG-110; REV P1; SHEET 1 of 1; SIZE ANSI B; SCALE 1:20; UNITS mm; PROJECTION; DRAWN Amish Chadha; MATERIAL / NOTES 304 pipe 48.3 x 3.68; Licensed CERN-OHL-S-2.0 · Design Molecule Lab · designmolecule.com; Generated from cad/src; do not edit by hand

WHERE IT GOES

This part in colour, its neighbours in grey

HOW TO MAKE IT AND HOW IT FITS
Saw 1550 long; deburr; round the near end edge with a file.
Drill 10 cross holes at 100 pitch along its whole length,
the first 50 from the near end, all in one line.
Mark each hole with the pit width it suits (punch marks).
Fits: slides inside the pivot tube; one lynch pin through both
tubes sets the reach; the far stand clamps on it in a split sleeve.
Not needed for pits up to 1.22 m wide.
Check: at least 250 of it stays inside the pivot tube when pinned.

Scale 1:20; looking down (along -Z)

Scale 1:20; looking at the front (along +Y)

Scale 1:20; looking at the right side (along -X)

VatReel: extension tube (make 1)

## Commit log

2026-10-03 VatReel at TRL 3: constructable design (kit 1.7.0)
    Problem, concept and requirements; sizing calculations; CAD model, STEP and STL; general arrangement drawing; bill of materials; build plan with making sketches, joint close-ups and step pictures; design decisions register (all decided under Amish's 2026-10-03 pre-approval); TRL 2 and TRL 3 review; photoreal renders and storefront card. Private until Amish opens it.
    [bearing-tower.step, bearing-tower.stl, bom.csv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]
2026-10-03 Carry Amish's 2026-10-03 requirement decisions into the design
    Amish chose option A on each requirement decision ("1A 2A 3A 4A 5A 6A 7A 8A 9A 10A 11A"). CampBreak: primed foot valve, pre-coupled suction hose and a drilled 30 s gather (R9 now 3.2 min at 100 m, me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

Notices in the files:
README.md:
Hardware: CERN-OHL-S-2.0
